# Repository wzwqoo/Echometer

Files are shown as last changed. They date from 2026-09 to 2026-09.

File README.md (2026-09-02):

# Echometer

A pocket-sized, battery-powered **ultrasonic bat detector**. It listens for
bat calls above 19 kHz, and when it hears one it records a 3.84-second
full-spectrum clip at **256 ksps** into PSRAM and serves it over its own Wi-Fi
network. Open a phone browser, download the WAV, and import it straight into
the Wildlife Acoustics **Echo Meter** app — the files carry GUANO metadata and
are accepted as Echo Meter Touch 2 Pro recordings.

No SD card, no cables, no custom phone app, no laptop in a field at midnight.

This is **v4**, the fourth board in the series. It is the first one that is
genuinely portable and the first one that doesn't clip on a close bat: the
analog front end has **six switchable gain steps from 22× to 782×**, chosen
from the web page or tracked automatically, and the whole thing runs off a
protected LiPo with charger and boost on board. See
[Design history](#design-history) for how it got here.

|  |  |
|:--:|:--:|
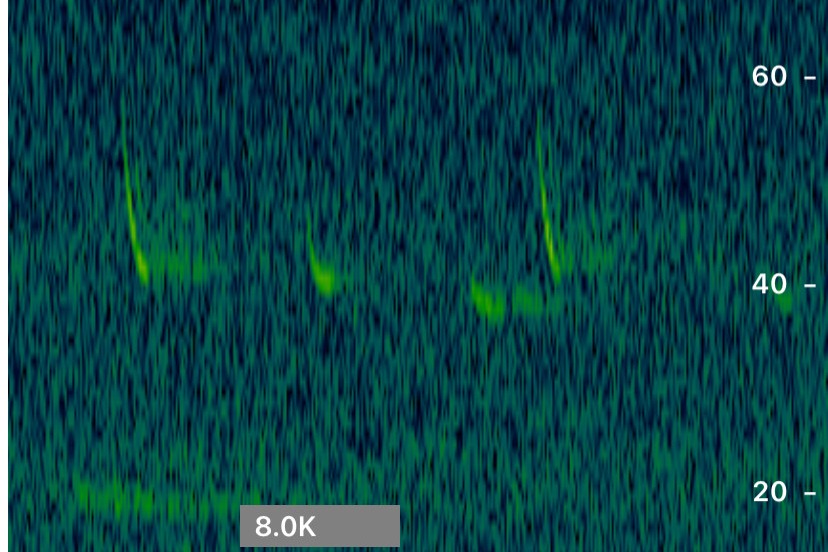
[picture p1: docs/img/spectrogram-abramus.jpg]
Echo Meter spectrogram of four downsweeping calls between roughly 40 and 55 kHz, on a 14-67 kHz axis
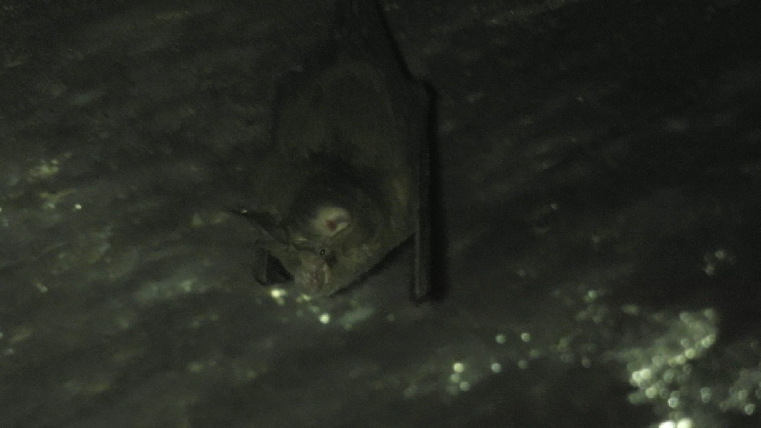
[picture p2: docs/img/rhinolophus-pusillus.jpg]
Least horseshoe bat roosting upside down on a cave ceiling
|  |  |
| **Japanese Pipistrelle**<br>*Alionoctula abramus* &mdash; recorded by this board, opened in the Echo Meter app | **Least Horseshoe Bat**<br>*Rhinolophus pusillus* &mdash; the ~108 kHz caller that set the sample rate |

---

## Contents

- [Specifications](#specifications)
- [How it works](#how-it-works)
- [Repository layout](#repository-layout)
- [Getting started](#getting-started)
- [Using it](#using-it)
- [Hardware in brief](#hardware-in-brief)
  - [Switchable gain](#switchable-gain)
  - [Power](#power)
  - [Pinout](#pinout)
- [Firmware in brief](#firmware-in-brief)
- [Errata — read before ordering the PCB](#errata--read-before-ordering-the-pcb)
- [Design history](#design-history)
- [Roadmap](#roadmap)
- [References](#references)

---

## Specifications

| | |
|---|---|
| Detection band | 19 – 128 kHz |
| Sampling | 256 ksps, 12-bit, external SAR ADC (ADCS7476) |
| Frequency resolution | 125 Hz/bin (2048-point FFT, 8 ms frames) |
| Analog gain | 6 steps, **22× – 782×** (26.9 – 57.9 dB), manual or AGC |
| Microphone | Knowles SPU0410LR5H-QB MEMS, −38 dBV/Pa, usable to ≈ 80 kHz |
| Clip length | 3.84 s (983 040 samples, 1.97 MB) |
| Clip storage | up to 8 PSRAM slots — 4 on an 8 MB module; RAM-only, lost at power-off |
| Transfer | open Wi-Fi AP `echometer` → `http://192.168.4.1` |
| File format | 16-bit mono WAV + GUANO chunk, `CHIRP_YYYYMMDD_HHMMSS.wav` |
| Compute | ESP32-S3 DevKitC-1, octal PSRAM, ESP-IDF ≥ 5.2 |
| Power | 2000 mAh LiPo, TP4056 charger @ 1 A, DW01/FS8205A protection, MT3608 boost |
| PCB | 4-layer, KiCad 10, gerbers in [`hardware/fab/`](hardware/fab/) |

## How it works

```text
                        ┌── 74HC4053 mux ──┐
                        │  (3 × GPIO)      │
                        ▼                  ▼
  ┌────────┐      ┌───────────┐      ┌──────────┐      ┌───────────┐
  │ conical│      │  OPA838   │      │  TL972   │      │ ADCS7476  │
──│  horn  │─────▶│  ×4.25/34 │─────▶│ ×5.2…23  │─────▶│ 12-bit    │
  │        │ MEMS │  stage 1  │  HP  │ stage 2  │  AA  │ 256 ksps  │
  └────────┘  mic └───────────┘      └──────────┘      └─────┬─────┘
                                                             │ I²S RX DMA
                                                             ▼
   Safari ◀── HTTP ◀── SoftAP ◀── PSRAM clip ◀── trigger ◀── 2048-pt FFT
     │                             4 × 3.84 s      >19 kHz    (esp-dsp)
     ▼                                             narrowband
  Echo Meter app                                   3 frames
```

1. Press **BOOT** to arm. The LED flashes green whenever ultrasound is present.
2. Every 2048-sample buffer is FFT'd. A detection needs a **narrowband** peak
   above 19 kHz that **persists** across 3 consecutive frames — broadband
   transients (a finger on the board, contact noise) are rejected.
3. On detection the clip streams into a PSRAM slot for 3.84 s. The LED goes
   completely silent during the write — its own drive current used to print
   evenly-spaced clicks into the spectrogram.
4. Blue flash when saved, then back to idle. Join Wi-Fi `echometer`, browse to
   `http://192.168.4.1`, download or delete clips, and set the gain.

The interesting trick is the ADC clocking. The ESP32-S3's internal ADC-DMA path
tops out near 83 ksps, nowhere near enough for a bat. So an external SAR ADC is
driven by the **I²S peripheral pretending to be an SPI master**: in 16-bit
stereo master mode the WS line toggles every 16 bit-clocks, so WS becomes the
ADC's `CS#` and BCK its `SCLK`. RX DMA captures every sample with zero
per-sample CPU, jitter-free, at an 8.192 MHz bit clock.

## Repository layout

| Path | Contents |
|---|---|
| [`hardware/`](hardware/) | KiCad 10 project — schematic, 4-layer PCB, gerbers, BOM, horn generator. See [hardware/README.md](hardware/README.md) for the analog design. |
| [`firmware/`](firmware/) | ESP-IDF application. See [firmware/README.md](firmware/README.md) for the detection logic and bring-up lessons. |
| [`firmware/main/archive/`](firmware/main/archive/) | Earlier firmware variants kept for reference — v3's original, an SD-card recorder, a board bring-up test. |
| [`docs/img/`](docs/img/) | Photographs and screenshots used in this README. |

## Getting started

**You need:** an ESP32-S3-DevKitC-1 with **octal** PSRAM, the assembled v4
board, a 2000 mAh LiPo with a JST-PH lead, and ESP-IDF ≥ 5.2.

```bash
cd firmware
. ~/software/esp-idf/export.sh              # adjust to your ESP-IDF path
idf.py build
idf.py -p /dev/ttyUSB0 flash monitor        # the COM (UART) USB-C port
```

The DevKitC-1 has two USB-C ports. **COM** (CP2102N → UART0) does flashing and
the log console and always works. If a bad flash ever bricks the app: hold
BOOT, tap RESET, release → ROM download mode, reflash over COM.

Before you build the board, read
[Errata](#errata--read-before-ordering-the-pcb) — item 1 is blocking.

## Using it

| Action | What happens |
|---|---|
| Press BOOT | Arm. LED flashes green while ultrasound is present. |
| Detection | LED silent, 3.84 s clip written to PSRAM, then blue flash. |
| Press BOOT while armed | Disarm back to idle. Presses during a write are ignored. |
| Join `echometer` (open network) | AP is up in every state. |
| `http://192.168.4.1` | Clip list, newest first: download, delete, set gain, toggle AGC. |

Clips live in RAM only — **they are lost at power-off**. Download before you
disconnect the battery.

To get a clip into the Echo Meter app on iOS: download in Safari, then
Files → share sheet → *Copy to Echo Meter*.

---

## Hardware in brief

Everything below is the summary. Full derivations — op-amp selection, mic
specs, the input common-mode budget, every filter corner, the power design,
the pinout, the acoustic horn and the bat call-level budgets — are in
[hardware/README.md](hardware/README.md).

Single channel, single 3.3 V analog rail, everything biased to mid-rail
(VREF ≈ 1.65 V). Stage 1 is a **TI OPA838** — 300 MHz GBW, decompensated,
1.8 nV/√Hz — because gain × 120 kHz has to fit inside the gain-bandwidth
product. Stage 2 is a **TI TL972**, rail-to-rail in and out, which drives the
ADC to full swing on 3.3 V. Both stages are non-inverting with a 1 kΩ leg to
VREF. The band is ≈ 19 kHz – 128 kHz: two 10 nF high-passes stacked at the
bottom, a 72 kHz RC anti-alias filter ahead of the ADC at the top.

### Switchable gain

A **74HC4053** analog mux switches extra feedback resistors **in parallel**
with a permanent one at each stage's summing node — one switch on stage 1, two
on stage 2. Parallel resistors *lower* the gain, the permanent resistors mean
the loop is never open, and the mux's Y0-when-LOW polarity means the state the
ESP32's GPIOs sit in at reset is **minimum gain, which cannot clip**.

| **Total** | dB | Clips near | Use |
|---|---|---|---|
| **22×** | 26.9 | 105 dB SPL | cave / roost, bats at arm's length |
| **51×** | 34.2 | 98 dB SPL | |
| **98×** | 39.8 | 92 dB SPL | general close work |
| **210×** | 46.4 | 86 dB SPL | default at cold boot |
| **408×** | 52.2 | 80 dB SPL | |
| **782×** | 57.9 | 74 dB SPL | distant passes, ~30 m |

Steps are 5.6–7.3 dB apart. "Clips near" is the input SPL at which the TL972
output hits its rail. The range stops at 782× because past ~800× you are
amplifying the microphone's own noise rather than signal — further reach has to
come from narrowband processing, not from the front end.

Resistor values, the switch-state table, why the three switches are split 1/2
across the stages, and why the switches sit at the summing node:
[hardware/README.md](hardware/README.md#gain--how-the-switching-works).

### Power

USB charger → cell → protection → boost to 5.31 V for the module, with the
analog rail taken off separately. The one decision worth naming here: **the
analog LDO is fed from the battery, not from the boost.** The TPS74801's
separate BIAS pin runs its control loop from +5 V so the pass FET can be driven
above VIN, which lets IN sit at the raw cell voltage. The win isn't efficiency,
it's noise — the analog rail never sees the MT3608's 1.2 MHz ripple, which no
LDO's PSRR is good at rejecting.

Two things to know before you use it:

- **Charging while running works**, but the load current means the TP4056 may
  never reach its termination threshold, so it can sit in CV at 4.2 V and the
  green LED may never come on. Don't leave it plugged in for days.
- **There is no power switch.** The board runs from the moment the cell is
  connected — unplug J6 to stop it. See errata 5 to store it charged.

Rail diagram, component values, the 5.31 V boost-margin calculation and where
to add a switch if you want one: [hardware/README.md](hardware/README.md#power).

### Pinout

ADC on GPIO 4 / 5 / 6 (I²S WS / BCK / DIN), gain select on GPIO 38 / 37 / 36
(⚠ **see errata 1**), RGB LED on 48, BOOT button on 0. Full header-pin table:
[hardware/README.md](hardware/README.md#pinout--esp32-s3-devkitc-1).

---

## Firmware in brief

ESP-IDF application, single `main.c`. Full detail — state machine, WAV/GUANO
construction, sdkconfig requirements and the bring-up lessons — is in
[firmware/README.md](firmware/README.md).

| State | Entered by | LED |
|---|---|---|
| IDLE | boot / disarm | off |
| DETECT | BOOT press | green flash while ultrasound present |
| RECORD | detection persists 3 frames | **silent** for the 3.84 s write |
| after RECORD | write finished | blue flash ~1.2 s → IDLE |

**Detection.** 2048-point real FFT per buffer via esp-dsp. Trigger requires, on
3 consecutive buffers: a bin above 19 kHz (bin ≥ 152) over
`ULTRASONIC_THRESH_COUNTS`, **and** a peak ≥ 20× the average power of the rest
of the >19 kHz band. The tonality test is what rejects broadband impulses; the
persistence test is what rejects momentary ones.

**Gain control.**

- **Web:** `http://192.168.4.1` → tap a gain. Picking one by hand turns the AGC
  off, and the choice is saved to NVS so it survives a power cycle.
- **AGC:** fast attack, slow decay. Any frame peaking above 90 % of full scale
  drops the gain one step immediately; the gain only steps back up after ~1 s
  (120 frames) below 10 %. Asymmetric on purpose — clipping happens in the
  **analog** domain before the ADC, so a clipped call is unrecoverable, while a
  symmetric AGC would pump on every gap between calls.
- **Frozen during RECORD.** A gain step mid-clip would put a discontinuity in
  the waveform and make the clip useless for absolute amplitude. The gain in
  force is latched at trigger time and written into the clip's GUANO metadata
  (`Note` plus `Echometer|Gain`), so SPL can be reconstructed offline.
- After every gain change the detector skips 2 frames while the mux's charge
  injection settles out of the summing node, so a switch is never mistaken for
  a call.

**HTTP endpoints:** `/` (clip list), `/dl`, `/del`, `/gain?i=N`, `/agc?on=0|1`.

**A note on the device identity in the metadata.** The Echo Meter app validates
the GUANO `Model` field against known Wildlife Acoustics modules and rejects
anything else, so the firmware writes `Model: Echo Meter Touch 2 Pro` — a
format this recorder genuinely matches (256 kHz, 16-bit, full-spectrum mono).
True provenance is kept in the GUANO `Note` field. Keep that in mind before
sharing files anywhere that trusts the device tag.

---

## Errata — read before ordering the PCB

Known problems with the v4 board as drawn. **Item 1 is blocking** — fix it in
the schematic before you send gerbers. The rest are things to know before you
build, not stop-ships.

**1. Two gain-select signals land on the octal-PSRAM bus.** With
`CONFIG_SPIRAM_MODE_OCT=y`, GPIO35/36/37 belong to the PSRAM controller and
cannot be used for anything else, but the PCB routes Gain S2 to J12.11
(GPIO37) and Gain S3 to J12.12 (GPIO36). The firmware already assumes the
corrected pins — `PIN_GAIN_S1/S2/S3` are GPIO 38/39/40 — so an uncorrected
board will not switch gain.
**Fix:** move S2 to J12.9 (GPIO39) and S3 to J12.8 (GPIO40). GPIO39/40 are
MTCK/MTDO, free here only because the DevKitC-1 debugs over the built-in
USB-Serial-JTAG on GPIO19/20. See
[firmware/README.md](firmware/README.md#5-gpio-choice-is-constrained-by-psram-mode).

**2. Stage 1's lowest gain step sits below the OPA838's minimum stable gain.**
The OPA838 is decompensated, with a minimum stable gain of +7; stage 1's low
setting is 4.25. The design relies on C14 (27 pF across R13) to provide the
compensation the topology needs, and 27 pF is small enough that stray
capacitance matters. If the three low gain steps ring, peak or oscillate,
this is the first place to look.

**3. The +5 V rail has ~390 mV of bias margin, and it needs verifying.** The
boost is set to 5.31 V because the TPS74801's BIAS pin must stay at least
1.62 V above the 3.3 V output, i.e. ≥ 4.92 V. Measure the sag on a real board:
if +5 V dips below 4.92 V during a Wi-Fi TX burst, the LDO loses bias headroom
and the analog rail glitches during exactly the moments you transmit.

**4. The SD footprint (J5) is +5 V and unbuffered.** Pin 5 is fed +5 V and the
SPI lines are not level-shifted, so J5 accepts an SD **module** with its own
regulator and level shifters — never a bare card socket. The current firmware
does not use it; leave it unpopulated unless you are building the archived
recorder.

**5. There is no power switch, and the cell will over-discharge in storage.**
The boost's EN is tied to its own input, so the board runs from the moment the
cell is connected. Standby drain as built is 50–120 mA, which flattens
2000 mAh in 17–40 hours and then parks the cell at the DW01's 2.4 V cutoff —
bad for lithium.
**Fix:** unplug J6 for storage and store the cell charged. If you add a switch,
put it in the `Lipo+ → L1 / U8.5` branch, **not** on the boost's EN pin — the
MT3608 is asynchronous, so `Lipo+ → L1 → D3 → +5V` is a permanent DC path that
survives disabling the boost. See
[hardware/README.md](hardware/README.md#charging-and-switching-both-with-caveats).

**6. Several schematic symbols carry stale part numbers.** R13, R23/R25, R24
and R26 inherit a 24 kΩ `Part#` / `LCSC Part #` from their previous value, and
C16 inherits a 10 nF one. Those fields are cleared in the checked-in
[`hardware/v4.csv`](hardware/v4.csv), so **ordering from the CSV is safe** —
but fix the symbol properties before the next `kicad-cli sch export bom`.

---

## Design history

Four boards, each one built to answer the question the previous one raised.

| | v1 | v2 | v3 | v4 |
|---|---|---|---|---|
| **Compute** | STM32F401CBU6 | STM32F446RET6 (Nucleo) | ESP32-S3 | ESP32-S3 |
| **Sampling** | internal ADC, free-running DMA | internal ADC, TIM2-gated **240 ksps** | external ADCS7476 via I²S, **256 ksps** | same |
| **Detection** | none — raw recorder | CMSIS-DSP FFT, >19 kHz threshold | + tonality + persistence | same |
| **Storage** | micro-SD (SPI1, FatFS) | micro-SD (SPI3, FatFS) | 4 × PSRAM slots | up to 8 slots |
| **Retrieval** | pull the card / USB CDC | pull the card / UART + Python | **Wi-Fi + Safari + GUANO WAV** | same |
| **Gain** | analog board, fixed | fixed 121× | fixed 625× | **6 steps, 22×–782× + AGC** |
| **Listening** | heterodyne + FD to a speaker | — | — | — |
| **Power** | 9 V in, LM2574 + LDOs | dev-board USB | USB (browned out) | **LiPo + charger + protection + boost** |

### v1 — does the analog even work?

A custom STM32F401CBU6 mainboard plus a separate analog board carrying the
classic hobbyist bat-detector chain: SPU0410 MEMS mic → LM358 preamp → CD4066
mixer switched by a TLC555 → LM386 → speaker, i.e. **heterodyne and frequency
division straight to your ears**. Two small preamp boards (one OPA838, one
TL972) were spun alongside it to compare op-amps on real signals.

The MCU side ran FreeRTOS with three tasks: ADC1 in continuous DMA into a
double buffer, a ring buffer feeding FatFS on a micro-SD over SPI1, and a
debounced button. Power was 9 V in through an LM2574 buck and NCP718/NCP163
LDOs.

**What it proved:** the microphone, the horn and the amplifier chain all work,
and you can hear bats. **What it cost:** hearing a bat isn't recording one —
the heterodyne path destroys the signal it demodulates. There was no detection
logic at all, so recording was start/stop by hand. The ADC free-ran on a
software start with no timer trigger, so the sample clock had jitter. And
splitting analog and digital across two boards joined by 4-pin headers was an
invitation to pickup.

**→ v2:** drop the speaker path entirely, go full-spectrum digital, put the ADC
on a hardware time base, and add a real FFT detector.

### v2 — detect it, don't just hear it

A Nucleo-F446RE with a custom analog + SD daughterboard: SPU0410 →
**OPA838 → TL972**, single 3.3 V rail, mid-rail bias — the two-stage topology
that survives into v4. TIM2 TRGO gates ADC1 at exactly **240 ksps** into a
2 × 2048 DMA double buffer, and each half-buffer goes through
`arm_rfft_fast_f32` from CMSIS-DSP: 117 Hz/bin, trigger on any bin ≥ 163
(>19 kHz) above 50 counts. Detect and record are two states with different LED
blink rates; recording writes raw `uint16` samples to FatFS over SPI3 with an
`f_sync` every 100 writes. Python tools (`bat_record.py`, `bat_viewer.py`,
`bat_waveform.py`) pull captures over the serial port and plot them.

Gain went from 11× per stage (**121×** total) to 25× per stage (**625×**)
during bring-up. At 121× real calls sat barely above the noise floor; the 5×
jump is what moved detection from marginal to reliable.

**What it cost:** 240 ksps means a 120 kHz Nyquist, and that was the internal
ADC's practical ceiling — the target species here, *Rhinolophus pusillus*, calls
at ~108 kHz, right at the edge. Getting files off meant pulling the card or
dumping over serial. And the gain was still a soldered constant.

**→ v3:** an external ADC fast enough to have real margin above 108 kHz, and a
way to get files onto a phone in the field.

### v3 — fast enough, and wireless

ESP32-S3 with an external **ADCS7476** 12-bit SAR clocked by the I²S
"WS-as-CS" trick at **256 ksps** — zero per-sample CPU, 128 kHz Nyquist.
Detection moved to esp-dsp and gained the two tests that make it usable
outdoors: **tonality** (peak bin ≥ 20× the mean power of the rest of the band)
and **persistence** (3 consecutive frames). Clips go to PSRAM — four 3.84 s
slots in 8 MB — and are served over a SoftAP as WAVs with a **GUANO** metadata
chunk that the Echo Meter iPhone app accepts. Two mics and two full channels,
fixed 625×.

That combination is what made it a real detector: no card, no cable, and a
phone app that already knows how to draw a spectrogram.

**What it cost, and this is the whole reason v4 exists:**

- **625× clipped constantly.** Roughly 9 out of 10 close calls railed the
  second stage, smearing the spectrogram into broadband bars and false
  harmonics. Clipping happens in the analog domain, so no amount of digital
  processing recovers it — and there was no way to turn the gain down.
- **It browned out.** Wi-Fi RF calibration and TX bursts (300–400 mA on top of
  octal PSRAM) tripped the brownout detector on marginal USB supplies. Inline
  USB "noise filter" dongles made it *worse* — series resistance is exactly the
  problem. Downloads, being the heaviest sustained RF load, failed first.
- **A floating ADC input false-triggered on touch.** Fixed in firmware by the
  tonality and persistence tests; the hardware fix was left for the next spin.
- **The LED printed clicks into the spectrogram.** The WS2812's RMT refresh
  coupled into the front end, so the firmware learned to keep it silent for the
  whole capture window.
- **The mic-supply filter did nothing.** 10 Ω + 110 nF corners at 159 kHz —
  above the band it was supposed to clean.

**→ v4:** make the gain adjustable, and stop feeding a 400 mA radio through a
thin cable.

### v4 — portable, and it doesn't clip

| Area | v3 | v4 |
|---|---|---|
| Gain | fixed 625× | **6 steps, 22×–782×**, web-selectable + AGC |
| Gain control | — | 74HC4053 mux at both summing nodes, 3 GPIOs |
| Channels | 2 mics, 2× OPA838 + 2× TL972 | 1 mic, 1× OPA838 + 1× TL972 — gain replaces the second channel |
| Power source | USB only | LiPo 2000 mAh + charger + protection + boost |
| Charging | — | TP4056 @ 1 A, red/green status LEDs |
| Cell protection | — | DW01 + FS8205A, low-side |
| 3V3 analog rail | LDO from 5 V (boost output) | LDO **from the battery**, bias from 5 V |
| Mic supply filter | 10 Ω + 110 nF (159 kHz — did nothing) | **100 Ω + 10 µF (159 Hz)** |
| Anti-alias | 100 Ω + 10 nF (159 kHz, above Nyquist) | **100 Ω + 22 nF (72 kHz)** |
| Wi-Fi burst reservoir | external | **470 µF on board** at the module header |
| Floating ADC input | v3 erratum — false triggers | driven from the op amp through 100 Ω; can't float |
| Clip metadata | timestamp only | **gain recorded in GUANO** |

The trade worth naming: v4 gives up v3's second channel. Two mics at two fixed
gains is the other classic way to get wide dynamic range — digitise both, keep
whichever didn't clip, zero AGC artifacts. One switched channel costs a mux and
some AGC logic but buys 31 dB of range instead of one fixed step, and it frees
the board area that paid for the battery.

## Roadmap

Carried forward, in rough order of value:

- **Ring buffer for pre-trigger audio.** The clip currently starts at the
  triggering buffer, so the calls *before* detection fired are lost. This is
  the single biggest capture upgrade left — every serious passive recorder
  keeps a few seconds of pre-roll.
- **Adaptive trigger.** A running noise-floor estimate (exponential moving
  average of ultrasonic-band energy) rather than the fixed
  `ULTRASONIC_THRESH_COUNTS`. Note that with variable gain a fixed threshold
  now means a *different* absolute sensitivity at each step, which makes this
  more pressing than it was in v3.
- **Call-shape gating.** Require a swept FM component, plausible duration
  (~2–20 ms) and inter-pulse interval, to reject bush-crickets and machinery.
  The tonality + persistence test is a first cut at this.
- **Duty cycling** for unattended overnight runs — light sleep between checks,
  or a low-power always-on trigger path that wakes full recording on a hit.
- **Pause the AP during capture**, so no TX spike or RF pickup can coincide
  with the 3.84 s sampling window.

For reference, AudioMoth uses a plain amplitude threshold; Song Meter /
Kaleidoscope use band-limited energy triggers; Anabat uses zero-crossing
frequency division; and the most advanced run an on-device CNN
(e.g. BatDetect2) to detect and classify in real time.

## References

- [GUANO metadata specification](https://guano-md.org)
- TI [OPA838](https://www.ti.com/lit/gpn/opa838), TL972, ADCS7476, TPS74801 datasheets
- Knowles SPU0410LR5H-QB datasheet and Ultrasonic Application Note AN17
- [AudioMoth](https://www.openacousticdevices.info/) — reference low-power design
- [BatDetect2](https://github.com/macaodha/batdetect2) — CNN call detection and classification

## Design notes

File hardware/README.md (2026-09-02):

# Hardware — analog front end, power, PCB and acoustics

KiCad 10 project (`v4.kicad_pro`, schematic + 4-layer PCB), fabrication outputs
in [`fab/`](fab/), BOM in [`v4.csv`](v4.csv), and the parametric acoustic-horn
generator [`ultrasonic_horn_freecad.py`](ultrasonic_horn_freecad.py).

The schematic is split over two sheets: `v4.kicad_sch` (root) and
`MCU.kicad_sch` (everything — front end, ADC, power, module headers).

> Read the errata in the [top-level README](../README.md#errata--read-before-ordering-the-pcb)
> before ordering. Item 1 is blocking: two of the three gain-select signals land
> on the octal-PSRAM bus and must be moved.

---

## Analog front end

### Transducer

**Knowles SPU0410LR5H-QB**, one fitted. An analog MEMS mic with usable response
through the target bat band; its raw output is small — tens of millivolts for a
loud, close call — so it must be amplified and biased into the ADC's input
range before sampling.

| Parameter | Value |
|---|---|
| Type | analog MEMS (SiSonic), bottom-port, omnidirectional |
| Sensitivity | −38 dBV/Pa (±3 dB) ≈ 12.6 mV/Pa @ 94 dB SPL, 1 kHz |
| SNR | 63 dB(A) → self-noise ≈ 31 dB(A) SPL |
| Frequency response | ~100 Hz → usable to ≈ 80 kHz (rising resonance ~20–25 kHz) |
| Max acoustic input | ≈ 120 dB SPL |
| Supply / current | 1.5–3.6 V / ~123 µA |
| Output impedance | ~200 Ω |
| Package | 3.76 × 2.95 × 1.10 mm, 0.25 mm port |

The 0.25 mm acoustic port sits at the throat of the conical horn.

### Op-amp choice

The amplifier must pass the full ultrasonic band **and** apply large gain
without rolling off, which sets a hard requirement on gain–bandwidth product:
`GBW ≥ gain × 120 kHz`. Two devices:

| Stage | Part | Why |
|---|---|---|
| 1st gain | **TI OPA838** (OPA838IDBVR) | 300 MHz GBW, decompensated (min stable gain +7), 1.8 nV/√Hz, ~1 mA |
| 2nd gain / ADC driver | **TI TL972** (TL972IDR) | dual rail-to-rail I/O, 12 MHz GBW — drives the ADC to full swing on 3.3 V |

Both run single-supply and bias the signal to **mid-rail (VREF ≈ 1.65 V)** so
the AC waveform swings symmetrically inside the ADC's 0–3.3 V window. A **TI
TPS74801** low-noise LDO supplies the analog rail and VREF, so digital
switching noise doesn't couple into the µV-level mic signal.

Note the OPA838's decompensation: its minimum stable gain is +7, which is a
real constraint on the gain-step table below — stage 1's low setting of 4.25
would be unstable on its own, and is only usable because C14 (27 pF across
R13) provides the compensation the topology needs.

### Gain — how the switching works

Both stages are non-inverting with a 1 kΩ leg to VREF. Each has a
**permanent** feedback resistor, and a **74HC4053** analog mux switches further
resistors in **parallel** with it, which *lowers* the gain.

| Stage | Amp | Rg | Permanent Rf | Switched in parallel | Gains |
|---|---|---|---|---|---|
| 1 | OPA838 (U3) | R6 = 1 k | R13 = 33 k | R26 = 3k6 via switch 1 | 34 / 4.25 |
| 2 | TL972B (U2) | R12 = 1 k | R25 = 22 k | R23 = 22 k (sw 2), R24 = 6k8 (sw 3) | 23 / 12 / 6.2 / 5.2 |

Three design decisions are load-bearing here:

**The permanent resistors are never switched out.** The loop is closed in every
mux state, including the ~300 ms before firmware runs and the instant the mux
transitions. Nothing can rail.

**The polarity is chosen so reset means quiet.** The 4053 selects Y0 — resistor
connected, parallel combination, *lower* gain — when its select pin is **LOW**.
GPIOs sit low at reset, so the board wakes at minimum gain, which cannot clip.

**The switches sit at the summing node**, mux common to the op-amp inverting
input and the resistors to Y0. Both sides of a closed switch are therefore at
virtual ground, so the mux's on-resistance sees an almost constant voltage.
That is what keeps the 4053's on-resistance nonlinearity out of the signal —
put the switch anywhere the voltage swings and it becomes a distortion source.

**Why the switches are split 1 / 2 across the stages.** Switching resistors in
parallel adds conductances, so the achievable ratio within one stage is bounded
— a single stage can only span about 18 dB however you pick the values. Two
stages multiply, giving the full 31 dB.

### The six steps

| S1 | S2 | S3 | Stage 1 | Stage 2 | **Total** | dB | Clips near |
|---|---|---|---|---|---|---|---|
| 0 | 0 | 0 | 4.25 | 5.2 | **22×** | 26.9 | 105 dB SPL |
| 0 | 0 | 1 | 4.25 | 12 | **51×** | 34.2 | 98 dB SPL |
| 0 | 1 | 1 | 4.25 | 23 | **98×** | 39.8 | 92 dB SPL |
| 1 | 1 | 0 | 34 | 6.2 | **210×** | 46.4 | 86 dB SPL |
| 1 | 0 | 1 | 34 | 12 | **408×** | 52.2 | 80 dB SPL |
| 1 | 1 | 1 | 34 | 23 | **782×** | 57.9 | 74 dB SPL |

Steps are 5.6–7.3 dB apart. "Clips near" is the input SPL at which the TL972
output hits its rail, for the SPU0410 at −38 dBV/Pa with ~1.45 V of peak swing.

Three switches give 8 states, not 6. The two omitted (177× and 26×) sit within
1.5 dB of a neighbour, and that bunching is unavoidable: the four states of two
parallel switches always satisfy `G(both) = G(a) + G(b) − G(neither)`, so they
cannot be spaced evenly.

### Input common-mode headroom — checked, and why VREF must stay mid-rail

Neither amp has a rail-to-rail *input* stage, and both stages are
non-inverting, so the + input carries signal rather than sitting still. On a
3.3 V rail:

| | Spec | Window on 3.3 V | Worst-case swing here | Margin |
|---|---|---|---|---|
| TL972 (U2) | V<sub>ICM</sub> = VCC− + 1.15 … VCC+ − 1.15 | **1.15 – 2.15 V** | 1.371 – 1.929 V (at A2 = 5.2) | 221 mV |
| OPA838 (U3) | VS− − 0 … VS+ − 1.3 (over temp) | **0 – 2.00 V** | 1.584 – 1.716 V | 284 mV |

Both pass. The TL972's is the tighter one and it appears at the *lowest* gain
step, where the output is clipping at ±1.45 V and its + input therefore has to
swing ±279 mV. The OPA838 is never stressed because its + input only ever
carries the mic-level signal, at most ±66 mV — the mic itself runs out
(AOP ≈ 120 dB SPL) at about the same point its 2.0 V ceiling would be reached.

The useful consequence: the safe window is the **intersection**, 1.15 – 2.00 V,
and VREF at 1.65 V sits near its centre. Do not "improve" headroom by moving
VREF down — 1.15 V is a hard floor for the TL972, and anything below ~1.4 V
starts eating the margin you gained at the top.

### Why the gain stops at 782×

The SPU0410's own noise integrated over 20–120 kHz is around **38 dB SPL**, and
a bat at 30 m arrives at roughly 30 dB SPL. Past ~800× you are amplifying mic
noise, not signal.

v3's jump from 121× to 625× helped because at 121× the ADC's LSB was still
competing with the mic noise; at 782× the mic dominates and more gain buys
nothing. Further range has to come from narrowband processing — FFT bin energy,
matched filter — not from the front end.

### Filtering — ultrasonic only

| Element | Value | Corner | Purpose |
|---|---|---|---|
| C12 + (R3 + mic Zout ≈ 1.3 k) | 10 nF | 12.2 kHz | HP, mic → stage 1 |
| C13 + (R15 + R10 ≈ 1.1 k) | 10 nF | 14.5 kHz | HP, stage 1 → stage 2 |
| *both together* | | **≈ 19 kHz −3 dB** | −33 dB at 2 kHz |
| C14 across R13 | 27 pF | 179 kHz | stage-1 LP / compensation |
| C15 across R25 | 27 pF | 268 kHz | stage-2 LP / compensation |
| R17 + C16 | 100 Ω + 22 nF | 72 kHz | anti-alias ahead of the ADC |
| R18 + C19 | 100 Ω + 10 µF | 159 Hz | mic **supply** filter (not signal) |

Two of these look similar and do opposite jobs, and v3 got one of them wrong.
R18/C19 is a **power-supply** filter on the mic's VDD pin — it wants its corner
far *below* the band, and 159 Hz gives about 48 dB of rejection at 40 kHz.
v3 used 10 Ω + 110 nF, which corners at 159 kHz and therefore did essentially
nothing. C12/C13 are the **signal** high-pass and want their corners *at* the
band edge.

The anti-alias filter had the same class of bug in v3: 100 Ω + 10 nF corners at
159 kHz, above the 128 kHz Nyquist, so it wasn't anti-aliasing anything. 22 nF
brings it to 72 kHz.

Keeping R6/R12 at 1 kΩ is what let both 27 pF compensation caps stay. Scaling
the network up 10× for resistor accuracy would have demanded ~2 pF caps, which
are not buildable against stray capacitance. Mux on-resistance instead adds
1.5 % error at the 33 k tap and 4 % at the 6k8 tap — irrelevant for a detector.

---

## Digital acquisition

Sampling is done by an **external 12-bit SAR ADC (ADCS7476, rated 1 MSPS)** run
at **256 ksps → 128 kHz Nyquist**, covering the full bat band. The ESP32-S3's
built-in ADC-DMA path tops out near 83 ksps — far too slow — so the external
ADC is clocked with a hardware trick:

- The **I²S peripheral** runs as master, 16-bit **stereo**, so its **WS line
  toggles every 16 bit-clocks**.
- **WS → ADC CS**, **BCK → SCLK**, **SDATA → I²S DIN**. WS-low frames each
  conversion (16 clocks readout); WS-high is the re-track gap.
- I²S RX DMA captures every sample jitter-free with **zero per-sample CPU**.
  At 256 ksps the bit clock is `256000 × 2 × 16 = 8.192 MHz`.

Buffers of **2048 samples** (one FFT frame, 8 ms) feed the detector —
125 Hz/bin resolution; the detection band starts at bin 152 (19 kHz). See
[../firmware/README.md](../firmware/README.md) for the detection logic and the
bit-alignment quirk in the returned word.

The ADC input is driven from the TL972 output through R17 (100 Ω), so unlike
v3 it can never float. A floating ADC input is an antenna, and touching it
false-triggered v3's detector every time.

### Signal levels & detection budget

| Quantity | Value |
|---|---|
| ADC | 12-bit, full scale 4095 counts over 3.3 V |
| Bias point | VREF ≈ 1.65 V |
| Raw transducer signal (close call) | ~33–50 mV |
| Gain range | 22× – 782×, six steps |
| Detection band | > 19 kHz |
| Known interferer | ~50 kHz USB switching noise falls **inside** the band |

The FFT detection threshold (`ULTRASONIC_THRESH_COUNTS`) sits a few dB above
the *amplified* noise floor. Because the gain is now variable, that fixed
count threshold represents a different absolute sensitivity at each step — see
the roadmap note about an adaptive trigger.

---

## Power

```text
USB ──▶ TP4056 ──▶ [cell] ──▶ DW01/FS8205 ──▶ Lipo+ ─┬─▶ MT3608 ──▶ +5V ──▶ ESP32 module
                                                     │              └──▶ TPS74801 BIAS
                                                     └──────────────────▶ TPS74801 IN ──▶ +3V3 analog
```

| Block | Part | Setting |
|---|---|---|
| Charger | TP4056 (U5) | R7 = 1.2 k → **1 A** (0.5 C into 2000 mAh); thermal pad on GND |
| Protection | DW01 (U6) + FS8205A (U7) | low-side, R20 100 Ω + C25 100 nF, R8 1 k on CS |
| Boost | MT3608 (U8) | L1 4.7 µH, D3 SS34, R21 150 k / R22 19.1 k → **5.31 V** |
| Analog LDO | TPS74801 (U10) | IN from Lipo+, BIAS + EN from +5 V, R11 31.2 k / R9 10 k → **3.30 V** |
| Wi-Fi reservoir | C28 470 µF | at the module header |
| Status | D1 red / D2 green | TP4056 CHRG / STDBY |

### The LDO is fed from the battery, not from the boost

That is the whole point of the TPS74801's separate BIAS pin. BIAS runs the
control loop and the gate driver, so the pass FET can be driven *above* VIN.
That lets IN sit at the raw cell voltage (3.0–4.2 V) and drop only ~50 mV at
the ~25 mA the analog side draws.

The win isn't efficiency — it's noise. Routed the obvious way (LDO fed from the
boost output), the analog rail inherits the MT3608's 1.2 MHz switching ripple,
and no LDO's PSRR is good at 1.2 MHz. Feeding it from the cell means the analog
rail never sees the switcher at all.

**Boost output is 5.31 V, not 5.0 V, and that is deliberate.** BIAS must stay
at least 1.62 V above the 3.3 V output, i.e. ≥ 4.92 V. At 5.1 V there was only
180 mV of margin — about what a Wi-Fi TX burst eats. Measure the sag on a real
board; if +5 V dips below 4.92 V during TX, the LDO loses bias headroom and the
analog rail glitches during exactly the moments you transmit.

### Charging and switching, both with caveats

**Charging while running works** — the cell buffers everything — but the load
current means the TP4056 may never see its termination threshold. It can sit in
CV at 4.2 V indefinitely and the green LED may never come on. Don't leave it
plugged in for days.

**There is no power switch.** The boost's EN is tied to its own input, so the
board runs from the moment the cell is connected; unplug J6 to stop it. Standby
drain as built is 50–120 mA, which flattens 2000 mAh in 17–40 hours and then
parks the cell at the DW01's 2.4 V cutoff — bad for storage.

If you add a switch, put it in the **`Lipo+ → L1 / U8.5` branch**, not on the
boost's EN pin. The MT3608 is asynchronous, so `Lipo+ → L1 → D3 → +5V` is a
permanent DC path: disabling the boost leaves the module's regulator powered
anyway. Breaking the boost input kills that path and still leaves the charger
connected.

---

## Pinout — ESP32-S3 DevKitC-1

| Function | Header pin | GPIO |
|---|---|---|
| ADC CS (I²S WS) | J11.4 | 4 |
| ADC SCLK (I²S BCK) | J11.5 | 5 |
| ADC SDATA (I²S DIN) | J11.6 | 6 |
| SD nCS / MOSI / SCK / MISO | J11.16–19 | 10 / 11 / 12 / 13 |
| +5 V / GND | J11.21 / J11.22 | — |
| Gain S1 | J12.10 | 38 |
| Gain S2 | J12.11 | 37 ⚠ move to J12.9 (GPIO39) |
| Gain S3 | J12.12 | 36 ⚠ move to J12.8 (GPIO40) |
| RGB LED | on module | 48 |
| Button | on module | 0 (BOOT) |

The SD lines are wired but unused by the current firmware; J5 must be an SD
**module** with its own regulator and level shifters, since it is fed +5 V on
pin 5 and the SPI lines are unbuffered.

---

## Acoustics — the conical horn

[`ultrasonic_horn_freecad.py`](ultrasonic_horn_freecad.py) is a parametric
generator for a conical horn that concentrates incoming ultrasound onto the mic
port. It is free SNR, ahead of the electronics.

| Parameter | Value |
|---|---|
| Profile | conical |
| Throat Ø (mic end) | 0.30 mm (just over the 0.25 mm mic port) |
| Mouth Ø (open end) | 28 mm (≈ 3.5 × wavelength at 45 kHz) |
| Length | 50 mm |
| Flare half-angle | ≈ 15.9° |
| Wall thickness | 0.5 mm |
| Optimised band | 40–50 kHz |
| Print | resin 25 µm (vertical), or FDM 0.12 mm / 100 % infill |

At 108 kHz the 28 mm mouth is ~8.8 wavelengths across — well above cutoff, so
the horn still delivers strong on-axis gain, just with a narrower beam that
must be aimed more precisely.

---

## Bat call levels, directivity and detection range

> Engineering **estimates** for sizing the front end — not species-accurate
> field data.

### Source levels

| Call type / example | Peak freq | SL @ 10 cm | ≈ @ 1 m | Notes |
|---|---|---|---|---|
| Loud open-air hawkers (*Nyctalus*, *Eptesicus*, *Pipistrellus*) | 25–50 kHz | 120–130 dB SPL | 100–110 dB SPL | loudest; FM/QCF sweeps |
| Horseshoe bats (*Rhinolophus*, CF) | 80–110 kHz | 105–120 dB SPL | 85–100 dB SPL | constant-frequency |
| "Whispering" gleaners (*Myotis*, *Plecotus*) | 40–90 kHz | 85–100 dB SPL | 65–80 dB SPL | very quiet, short range |

Cross-reference this against the "clips near" column in the gain table: a loud
hawker at a few metres wants the 22× or 51× step, while a distant pass wants
782×. That 31 dB spread is exactly the range v3's single fixed 625× could not
cover.

### Target species — least horseshoe bat (*Rhinolophus pusillus*)

| Parameter | Value |
|---|---|
| Call type | CF–FM (long constant-frequency tone + short FM tails) |
| Dominant CF | ≈ 106–112 kHz (~108 kHz typical) |
| Source level | moderate, ~80–90 dB SPL @ 1 m |
| FFT bin at 108 kHz | ≈ 864 (of 1024) — comfortably under the 128 kHz Nyquist |
| Est. on-axis range | **~7–9 m** (air absorption ~3.9 dB/m at this frequency) |

Consequences for the design:

- **A fast external ADC is mandatory.** At 108 kHz the call needs > 216 ksps;
  an MCU's internal ADC at 83 ksps could not see this species at all, and even
  v2's 240 ksps left it at the very edge of the band. Hence the ADCS7476 at
  256 ksps.
- **The narrowband CF tone is the easy case for the FFT detector** — its energy
  piles into one bin. Narrowing the detection window to ~100–115 kHz (bins
  ~800–920) would target this species specifically and reject the ~50 kHz USB
  noise interferer entirely.

### Directivity

| Source of directivity | Typical | Effect |
|---|---|---|
| Bat call emission | forward lobe, −3 dB half-angle ~30–40° | a bat not facing you arrives 10–20 dB weaker |
| Bare SPU0410 mic | omnidirectional | no aiming, no acoustic gain |
| With conical horn | directional lobe | +on-axis SNR/range, must be pointed |

### Estimated detection range

Loud bat, SL = 110 dB SPL @ 1 m on-axis; minimum detectable ≈ 40 dB SPL:

| Frequency | Air absorption α | Est. max range |
|---|---|---|
| 20 kHz | ~0.6 dB/m | ~60 m |
| 40 kHz | ~1.3 dB/m | ~30 m |
| 80 kHz | ~2.9 dB/m | ~16 m |
| 120 kHz | ~4.2 dB/m | ~12 m |

Optimistic ceilings — quiet bats, off-axis calls, and weather cut these
substantially.

---

## Bill of materials

Full BOM in [`v4.csv`](v4.csv), regenerated from the schematic with
`kicad-cli sch export bom`. The parts that define the design:

| Part | Qty | Role |
|---|---|---|
| SPU0410LR5H-QB | 1 | MEMS ultrasonic microphone |
| OPA838IDBVR | 1 | 1st gain stage (300 MHz GBW) |
| TL972IDR | 1 | 2nd gain / ADC driver (RRIO) |
| 74HC4053D | 1 | 3× SPDT analog mux — the gain switch |
| ADCS7476AIMFX/NOPB | 1 | 12-bit 1 MSPS SAR ADC |
| TPS74801DRCR | 1 | low-noise LDO (analog rail / VREF) |
| TP4056 | 1 | LiPo charger, 1 A |
| DW01 + FS8205A | 1 + 1 | cell protection |
| MT3608 | 1 | boost to 5.31 V |
| conical horn (`ultrasonic_horn_freecad.py`) | 1 | acoustic gain / directivity |

**Known BOM issue:** several passive symbols still carry the `Part#` and
`LCSC Part #` of their *previous* value — R13, R23/R25, R24 and R26 inherit a
24 kΩ part number, and C16 inherits a 10 nF one. Those fields are cleared in
the checked-in `v4.csv`, so ordering from it is safe, but fix the symbol
properties before the next export.

`altium_ascii_to_kicad.py` is a helper for importing Altium ASCII footprints
into the KiCad library; it is not part of the build.

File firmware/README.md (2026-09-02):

# Firmware — ESP32-S3 chirp catcher

ESP-IDF (≥ 5.2) application. On a button press it arms an FFT-based ultrasonic
detector; on detection it records a 3.84 s clip at 256 ksps into PSRAM and
serves it as an Echo-Meter-compatible WAV over a Wi-Fi SoftAP. The analog gain
is switched from the same web page, or tracked automatically.

Everything lives in [`main/main.c`](main/main.c).

## Build & flash

```bash
. ~/software/esp-idf/export.sh   # ESP-IDF >= 5.2
idf.py build
idf.py -p /dev/ttyUSB0 flash monitor
```

The DevKitC-1 has two USB-C ports: **COM** (CP2102N → UART0) is used for
flashing *and* the log console and always works; **USB** (native OTG,
GPIO19/20) is unused by the current firmware. If a bad flash ever bricks the
app: hold BOOT, tap RESET, release — ROM download mode, reflash over COM.

Key sdkconfig settings (already in the checked-in `sdkconfig`):

| Setting | Value | Why |
|---|---|---|
| `CONFIG_SPIRAM` + `_MODE_OCT` + `_SPEED_80M` | y | octal PSRAM for clip slots (quad modules: use `_MODE_QUAD`, 2 MB → 1 slot) |
| `CONFIG_ESP_CONSOLE_UART_DEFAULT` (UART0) | y | console on the COM port |
| `CONFIG_PARTITION_TABLE_CUSTOM` | `partitions.csv` | 4 MB factory app |

Wi-Fi TX power is left at the default max — see lesson 2 for why the earlier
cap was removed.

## State machine & LED

| State | Entered by | LED |
|---|---|---|
| IDLE | boot / disarm | off |
| DETECT (armed) | BOOT button press | off while quiet, **green flash** while ultrasonic is being detected |
| RECORD | detection persists 3 FFT frames | **off/silent** for the 3.84 s write (see below) |
| after RECORD | write finished | **blue flash** ~1.2 s, then off → IDLE |
| error (no PSRAM slot, …) | — | red blink |

**Why the LED is off during RECORD:** the WS2812 is driven over RMT on GPIO48,
and every refresh is a pulse burst that couples into the high-gain analog front
end — a periodic LED refresh during capture printed evenly-spaced broadband
clicks into the spectrogram. So the LED only ever refreshes *outside* the
sampling window: green while detecting (before the clip), silent during the
write, blue flash after. `LED_OFF` touches the strip once on entry then stays
completely idle.

Pressing the button in DETECT disarms back to IDLE; presses during RECORD are
ignored. Wi-Fi (`echometer`, open, `http://192.168.4.1`) is up in every state.

## Signal path

- **ADC via I²S "WS-as-CS".** The S3's internal ADC tops out around 83 ksps,
  far too slow. An external ADCS7476 (12-bit SAR) is clocked by the I²S
  peripheral in 16-bit stereo master mode — WS toggles every 16 bit-clocks and
  drives the ADC's CS, BCK drives SCLK, and RX DMA captures SDATA with zero
  per-sample CPU. At 256 ksps the bit clock is 8.192 MHz; usable Nyquist is
  128 kHz. One 16-bit sample per WS period, so the "left" slot is the data and
  the right is discarded.
- **Bit alignment.** The ADC emits 4 leading zeros then D11..D0, and standard
  I²S delays MSB by one BCK, so the word arrives shifted. Mask and shift in
  firmware rather than fighting the peripheral.
- **Detection.** 2048-point real FFT (esp-dsp) per buffer — 125 Hz/bin, 8 ms
  per frame. Trigger requires, on `DETECT_CONSEC` = 3 consecutive buffers: a
  bin above 19 kHz (bin ≥ 152) over `ULTRASONIC_THRESH_COUNTS`, **and** a peak
  ≥ `CHIRP_TONALITY_MIN` = 20× the average power of the rest of the >19 kHz
  band. See lesson 3 for why both tests exist.
- **Clips.** `CLIP_BUFS` = 480 buffers = 983 040 samples = 3.84 s = 1.97 MB.
  Slots are allocated from PSRAM at boot — up to `MAX_CLIP_SLOTS` = 8, stopping
  when free PSRAM would drop below `SPIRAM_RESERVE` = 512 kB, so an 8 MB module
  yields four. Oldest is overwritten. **Clips are RAM-only and lost at
  power-off.**
- **WAV serving.** 44-byte PCM header + samples + a trailing **GUANO** metadata
  chunk; filenames `CHIRP_YYYYMMDD_HHMMSS.wav`. There is no RTC on board — the
  clock is seeded from the firmware build time at boot.

## Gain control

New in v4. Three GPIOs drive a 74HC4053 that switches feedback resistors in
parallel at both amplifier stages; see
[../hardware/README.md](../hardware/README.md) for the analog side.

| | |
|---|---|
| `PIN_GAIN_S1/S2/S3` | GPIO **38 / 39 / 40** (note: the PCB routes S2/S3 to 37/36 — see errata 1 in the top-level README) |
| `GAIN_STEPS[]` | the six-step table, each with its 4053 levels, total gain and approximate clipping SPL |
| `GAIN_DEFAULT` | index 3 = 210× — a sane cold start |
| `gain_apply()` / `gain_init()` | drives the three GPIOs; restores the saved step from NVS |
| `agc_update()` | fast-attack / slow-decay tracker, returns true when it moved |
| `/gain?i=N` | set a step, and turn the AGC off |
| `/agc?on=0\|1` | toggle the AGC |
| `clip_slot_t.gain` | latched at trigger, shown in the clip list, written to GUANO |

**The AGC is asymmetric on purpose.** Any frame peaking above
`AGC_ATTACK_LEVEL` (90 % of full scale) drops the gain one step *immediately*;
the gain only steps back up after `AGC_DECAY_FRAMES` = 120 frames (~1 s) below
`AGC_DECAY_LEVEL` (10 %). Clipping happens in the analog domain, before the
ADC, so a clipped call is unrecoverable and worth reacting to instantly — while
a symmetric AGC would pump on every gap between calls.

**The gain is frozen during RECORD.** A step mid-clip would put a discontinuity
in the waveform and make the clip useless for absolute amplitude. The step in
force is latched at trigger time and written into GUANO (`Note` plus a
namespaced `Echometer|Gain` field), so SPL can be reconstructed offline.

**Settling.** After every gain change the detector skips `GAIN_SETTLE_FRAMES`
= 2 frames while the mux's charge injection settles out of the summing node,
so a switch is never mistaken for a call.

**Persistence.** The chosen step and the AGC on/off flag are stored in NVS
under the `echometer` namespace, so a hand-picked gain survives a power cycle.

## HTTP interface

| Endpoint | Purpose |
|---|---|
| `/` | clip list, newest first, with gain shown per clip; gain and AGC controls |
| `/dl?…` | download a clip as WAV |
| `/del?…` | delete a clip |
| `/gain?i=N` | select gain step N (0–5); implicitly disables the AGC |
| `/agc?on=0\|1` | enable/disable the AGC |

The server uses 30 s send/receive timeouts so a brief link stall doesn't kill a
2 MB download.

## `main/archive/`

Older firmware variants, kept for reference (not built):

- `main_v3.c` — the unmodified v3 application, before the gain layer. Useful as
  a diff base.
- `main_sd.c` — the original SD-card / USB-CDC recorder (detect → record raw
  samples to FatFS or stream over TinyUSB CDC). Needs `sdmmc fatfs vfs` in
  CMake REQUIRES plus the `espressif/esp_tinyusb` managed component, TinyUSB
  CDC enabled in menuconfig, and a **FAT32** (not exFAT) SD card.
- `main_test.c` — minimal board bring-up test (button → sample + FFT → green
  LED on detect, ADC stats on the console).

To build one, copy it over `main/main.c` and restore the dependencies noted in
`main/CMakeLists.txt`.

---

## Lessons learned

### 1. Getting WAVs accepted by the Echo Meter iPhone app

- A bare PCM WAV is **rejected**. The app wants **GUANO metadata**
  ([guano-md.org](https://guano-md.org)): a `guan` RIFF chunk with `Timestamp`,
  `Samplerate`, `Length`, `Make`, `Model`.
- With honest `Make: DIY / Model: echometer-v4` the import fails with
  *"invalid module type"* — the app validates `Model` against known Wildlife
  Acoustics modules. Identifying as `Echo Meter Touch 2 Pro` (whose format —
  256 kHz, 16-bit, full-spectrum mono — this firmware genuinely matches) makes
  imports succeed. True provenance is kept in a GUANO `Note` field. Keep this
  in mind before sharing files anywhere that trusts the device tag.
- 256 ksps was chosen over v2's 240 ksps partly for this compatibility.
- Their filename convention `PREFIX_YYYYMMDD_HHMMSS.wav` is also worth matching
  — sessions are organised by parsed timestamp.
- Import path on iOS: Files → share sheet → *Copy to Echo Meter*. The
  `Imported Files Session.kml` the app produces is a GPS **export**, not an
  import requirement.
- iPhone file transfer without a custom app: BLE is a dead end (the S3 has no
  Bluetooth Classic; iOS has no standard BLE file-receive; nRF Connect only
  logs hex at ~10 kB/s). **SoftAP + a tiny HTTP server + Safari** is the way.

### 2. Power / brownout

Mostly fixed in v4's hardware, but the reasoning is worth keeping:

- Enabling Wi-Fi *and* octal PSRAM pushed a marginal USB supply over the edge:
  `E BOD: Brownout detector was triggered` right at Wi-Fi RF calibration (the
  biggest current spike, 300–400 mA on top of everything else).
- An inline USB "noise filter" dongle made it worse — those add series
  resistance and limit current. Straight into a PC port worked.
- **Capping TX power was tried and removed.** `CONFIG_ESP_PHY_MAX_WIFI_TX_POWER`
  = 10 dBm (plus a runtime `esp_wifi_set_max_tx_power()`) did soften the
  calibration spike, but a weaker link forces retransmits that keep the radio
  on *longer* — 2 MB clip downloads got slow and aborted mid-file. Both were
  removed; TX power runs at the default max and power is fixed on the supply
  side instead.
- Downloads are the heaviest sustained RF load the board ever sees — heavier
  than boot — so if boot is marginal, downloads fail first.
- The firmware still starts Wi-Fi ~2 s after boot (see `app_main`) so the
  boot/PSRAM inrush and the RF-cal spike don't stack. v4 adds a 470 µF
  reservoir at the module header and a battery instead of a cable.

### 3. False triggers from a floating analog input

- Touching v3's floating ADC input false-triggered the detector every time: a
  finger/contact transient is a **broadband impulse** that lifts every FFT bin
  at once, and a single-bin amplitude threshold can't tell it from a call.
- Firmware fix, both in the DETECT loop: **tonality** — the peak bin must be
  ≥ 20× the mean power of the rest of the >19 kHz band; **persistence** — 3
  consecutive frames (~26 ms) must pass before recording. Real chirps are
  narrowband and sustained; touches are flat and momentary.
- v4 fixes it in hardware too: the ADC input is driven from the TL972 through
  R17 (100 Ω) and cannot float. The two firmware tests are still worth keeping
  — they also reject wind, handling noise and machinery transients.

### 4. ESP-IDF / toolchain gotchas

- `led_strip` 2.x uses `.led_pixel_format = LED_PIXEL_FORMAT_GRB`; the
  `color_component_format` field only exists in 3.x. Match the code to the
  version in `dependencies.lock`, not to the latest docs.
- A **trailing space** typed into the menuconfig field for the custom partition
  CSV produced `CONFIG_PARTITION_TABLE_CUSTOM_FILENAME="partitions.csv "` and a
  baffling ninja error (`'…/partitions.csv ' … missing and no known rule to
  make it`). menuconfig keeps whatever you type.
- TinyUSB CDC is **not** enabled by default (`CONFIG_TINYUSB_CDC_ENABLED`) —
  the archived USB-streaming main silently needs it, plus the secondary console
  set to *None*, since USB-Serial-JTAG and TinyUSB share GPIO19/20.
- SD cards for the archived recorder must be **FAT32/MBR** (`mkfs.vfat -F 32`);
  cards over 32 GB ship exFAT, which IDF's FatFS won't mount by default.

### 5. GPIO choice is constrained by PSRAM mode

With `CONFIG_SPIRAM_MODE_OCT=y`, **GPIO35/36/37 belong to the PSRAM
controller** and cannot be used for anything else. This is why the gain-select
pins are 38/39/40 in firmware even though the v4 PCB routes two of them to
36/37 — see errata 1 in the [top-level README](../README.md#errata--read-before-ordering-the-pcb).
GPIO39/40 are MTCK/MTDO, free here only because the DevKitC-1 debugs over the
built-in USB-Serial-JTAG on GPIO19/20.

---

## Still to do

- **Ring buffer for pre-trigger audio** — the clip currently starts at the
  triggering buffer, so the calls *before* detection fired are lost. The single
  biggest capture upgrade left.
- **Adaptive trigger** — a running noise-floor estimate rather than the fixed
  `ULTRASONIC_THRESH_COUNTS`. With variable gain, a fixed count threshold means
  a *different* absolute sensitivity at each step, so this matters more now
  than it did in v3.
- **Call-shape gating** — require a swept FM component, plausible duration
  (~2–20 ms) and inter-pulse interval, to reject bush-crickets and machinery.
- **Duty cycling** for unattended overnight runs.
- **Pause the AP during the 3.84 s capture**, so no TX spike or RF pickup can
  coincide with sampling.

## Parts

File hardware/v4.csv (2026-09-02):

Designator | Qty | Value | Part# | LCSC Part # | Footprint | Datasheet
C1,C10,C26,C29 | 4 | 22uF | x | x | Capacitor_SMD:C_0805_2012Metric
C2,C4,C12,C13,C17 | 5 | 10nF | CC0805JKNPO9BN103 | C527201 | Capacitor_SMD:C_0805_2012Metric
C5,C18,C19,C24,C30 | 5 | 10uF | x | x | Capacitor_SMD:C_0805_2012Metric
C6,C7,C8,C9,C11,C20,C22,C23,C25,C27,C31 | 11 | 100nF | x | x | Capacitor_SMD:C_0805_2012Metric
C14,C15 | 2 | 27pF | x | x | Capacitor_SMD:C_0805_2012Metric
C16 | 1 | 22nF | x | x | Capacitor_SMD:C_0805_2012Metric
C21 | 1 | 2.2uF | x | x | Capacitor_SMD:C_0805_2012Metric
C28 | 1 | 470uF | x | x | Capacitor_SMD:C_Elec_10x10.2
D1 | 1 | RED |  |  | LED_SMD:LED_0805_2012Metric
D2 | 1 | GREEN |  |  | LED_SMD:LED_0805_2012Metric
D3 | 1 | D_Schottky SS34 |  |  | Diode_SMD:D_SMA
J1 | 1 | USB_B_Micro |  |  | Connector_USB:USB_Micro-B_Molex-105017-0001
J5 | 1 | Conn_01x06_Socket | x | x | Connector_PinSocket_2.54mm:PinSocket_1x06_P2.54mm_Vertical
J6 | 1 | Conn_01x02_Socket | x | x | Connector_JST:JST_PH_B2B-PH-K_1x02_P2.00mm_Vertical
J11,J12 | 2 | Conn_01x22_Socket | ZX-PM2.54-1-22PY | C7499337 | Connector_PinSocket_2.54mm:PinSocket_1x22_P2.54mm_Vertical
L1 | 1 | 4.7uH | SL0420-4R7M | C22463808 | Inductor_SMD:L_TechFuse_SL0420
R1,R2,R9 | 3 | 10K |  |  | Resistor_SMD:R_0805_2012Metric
R3,R6,R10,R12 | 4 | 1K | x | x | Resistor_SMD:R_0805_2012Metric
R4,R5,R8 | 3 | 1k |  |  | Resistor_SMD:R_0805_2012Metric
R7 | 1 | 1.2k |  |  | Resistor_SMD:R_0805_2012Metric
R11 | 1 | 31K2 | x | x | Resistor_SMD:R_0805_2012Metric
R13 | 1 | 33K | x | x | Resistor_SMD:R_0805_2012Metric
R15,R17,R18,R20 | 4 | 100 | x | x | Resistor_SMD:R_0805_2012Metric
R16 | 1 | 22 | x | x | Resistor_SMD:R_0805_2012Metric
R19 | 1 | 0R |  |  | Resistor_SMD:R_0805_2012Metric
R21 | 1 | 150K |  |  | Resistor_SMD:R_0805_2012Metric
R22 | 1 | 19.1K |  |  | Resistor_SMD:R_0805_2012Metric
R23,R25 | 2 | 22K | x | x | Resistor_SMD:R_0805_2012Metric
R24 | 1 | 6K8 | x | x | Resistor_SMD:R_0805_2012Metric
R26 | 1 | 3K6 | x | x | Resistor_SMD:R_0805_2012Metric
U1 | 1 | SPU0410LR5H-QB | x | x | wzw:XDCR_SPU0410LR5H-QB | https://www.digikey.com/en/products/detail/syntiant/SPV0142LR5H-1/13901275
U2 | 1 | TL972IDR | TL972IDR | C46127 | Package_SO:SOIC-8_3.9x4.9mm_P1.27mm
U3 | 1 | OPA838IDBVR | OPA838IDBVR | C2058363 | Package_TO_SOT_SMD:SOT-23-6 | https://www.ti.com/lit/gpn/opa838
U4 | 1 | adcs7476aimfx/nopb | ADCS7476AIMFX/NOPB | C91530 | Package_TO_SOT_SMD:SOT-23-6_Handsoldering | https://www.ti.com/cn/lit/gpn/adcs7478
U5 | 1 | TP4056 |  |  | Package_SO:SOIC-8-1EP_3.9x4.9mm_P1.27mm_EP2.29x3mm
U6 | 1 | DW01 |  |  | Package_TO_SOT_SMD:SOT-23-6
U7 | 1 | FS8205A |  |  | Package_TO_SOT_SMD:SOT-23-6
U8 | 1 | MT3608 |  |  | Package_TO_SOT_SMD:SOT-23-6 | https://www.olimex.com/Products/Breadboarding/BB-PWR-3608/resources/MT3608.pdf
U9 | 1 | 74HC4053D_653 |  |  | SO16_SOT109-1_NEX | 74HC4053D_653
U10 | 1 | TPS74801DRCR | TPS74801DRCR | C105263 | Package_SON:VSON-10-1EP_3x3mm_P0.5mm_EP1.65x2.4mm

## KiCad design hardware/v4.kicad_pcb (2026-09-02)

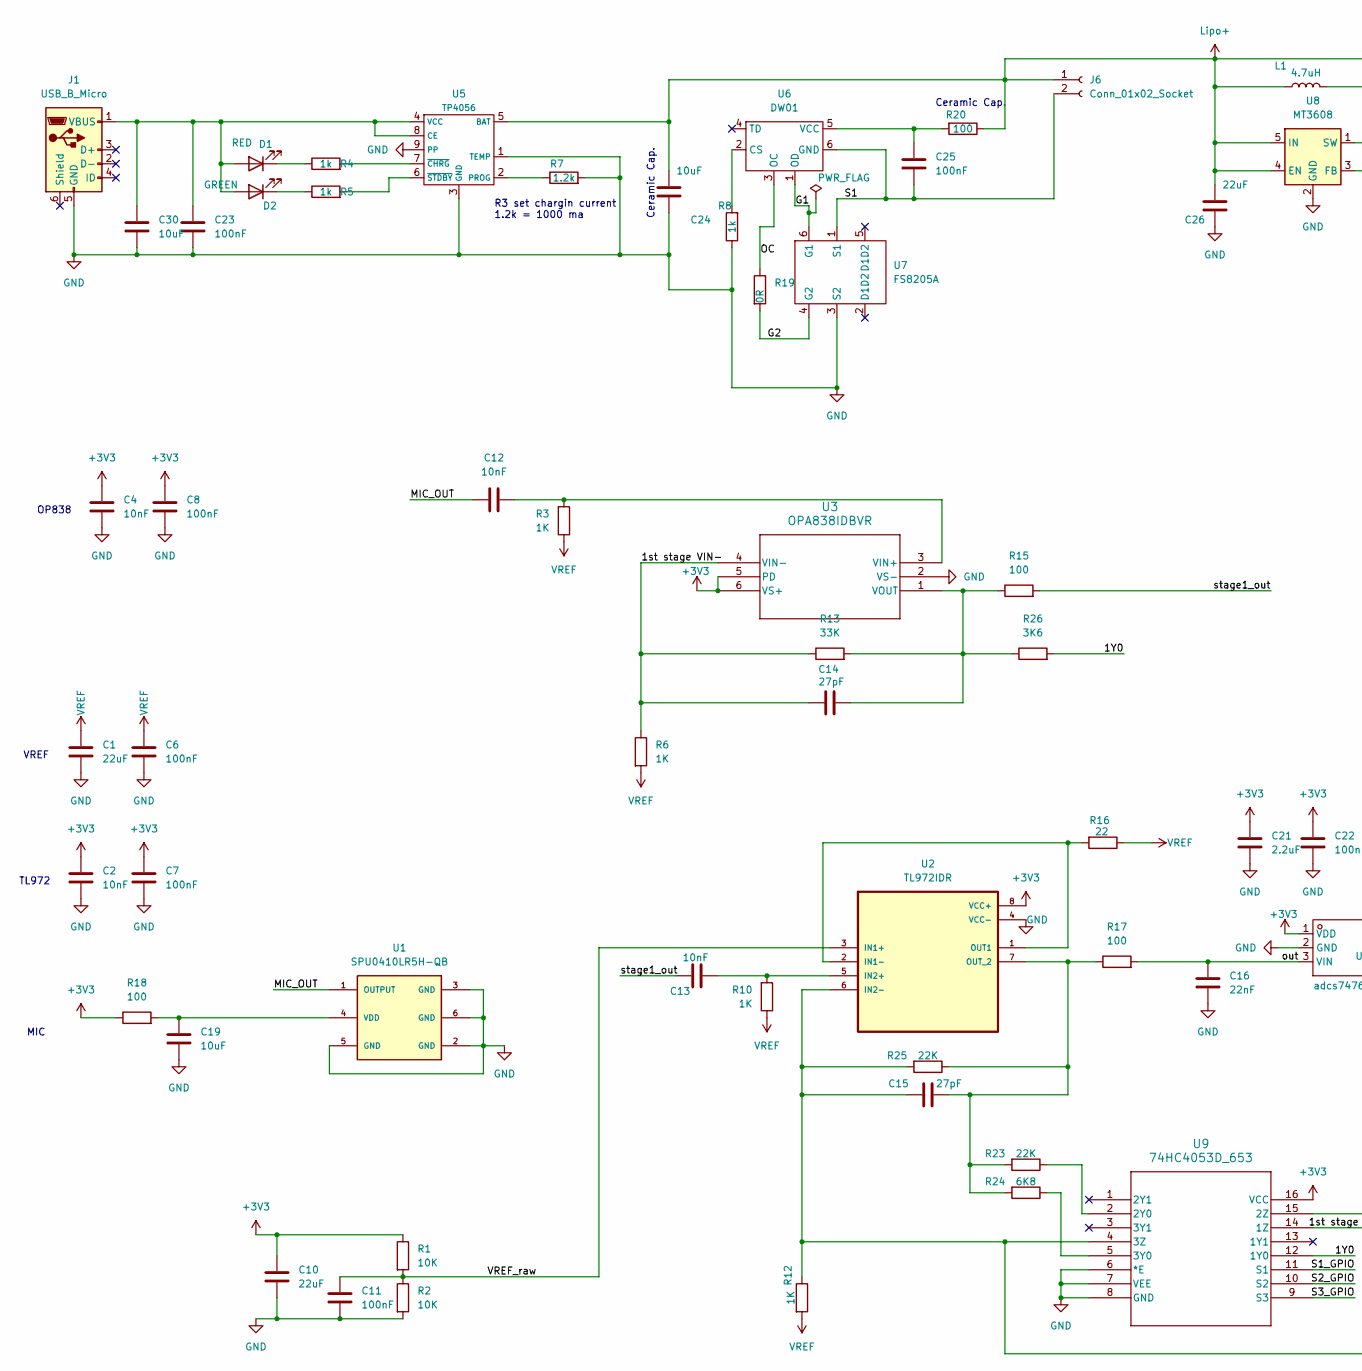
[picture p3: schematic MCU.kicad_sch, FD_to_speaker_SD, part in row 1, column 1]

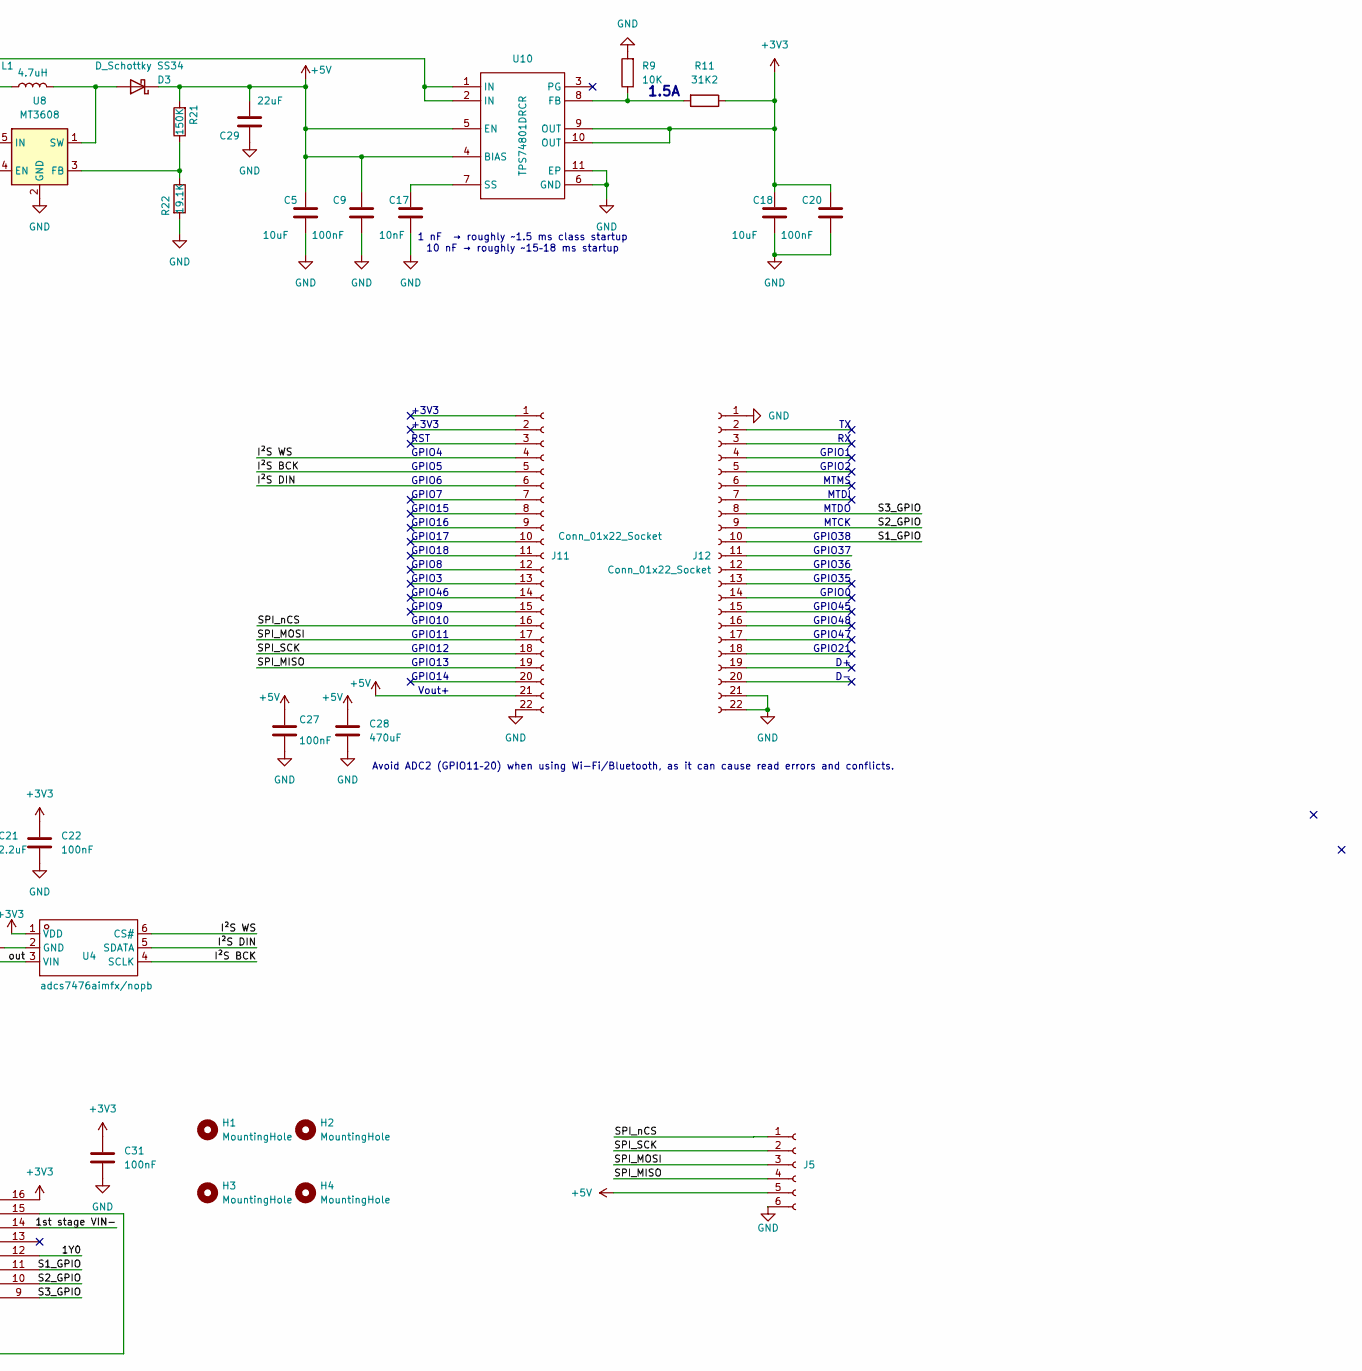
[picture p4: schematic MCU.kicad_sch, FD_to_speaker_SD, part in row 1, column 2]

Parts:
C1, C10: 22uF; C_0805_2012Metric; Part# x; LCSC Part # x
C2, C4, C12, C13, C17: 10nF; C_0805_2012Metric; Part# CC0805JKNPO9BN103; LCSC Part # C527201
C5, C18: 10uF; C_0805_2012Metric; Part# x; LCSC Part # x
C6, C7, C8, C9, C11, C20, C22, C27, C31: 100nF; C_0805_2012Metric; Part# x; LCSC Part # x
C14, C15: 27pF; C_0805_2012Metric; Part# x; LCSC Part # x
C16: 22nF; C_0805_2012Metric; Part# CC0805JKNPO9BN103; LCSC Part # C527201
C19: 10uF; C_0805_2012Metric; Part# CC0805JKNPO9BN103; LCSC Part # C527201
C21: 2.2uF; C_0805_2012Metric; Part# x; LCSC Part # x
C23, C25: 100nF; C_0805_2012Metric
C24, C30: 10uF; C_0805_2012Metric
C26, C29: 22uF; C_0805_2012Metric
C28: 470uF; C_Elec_10x10.2; Part# x; LCSC Part # x
D1: RED; LED_0805_2012Metric
D2: GREEN; LED_0805_2012Metric
D3: D_Schottky SS34; D_SMA
H1, H2, H3, H4: MountingHole; MountingHole_2.1mm; Part# x; LCSC Part # x
J1: USB_B_Micro; USB_Micro-B_Molex-105017-0001
J5: Conn_01x06_Socket; PinSocket_1x06_P2.54mm_Vertical; Part# x; LCSC Part # x
J6: Conn_01x02_Socket; JST_PH_B2B-PH-K_1x02_P2.00mm_Vertical; Part# x; LCSC Part # x
J11, J12: Conn_01x22_Socket; PinSocket_1x22_P2.54mm_Vertical; Part# ZX-PM2.54-1-22PY; LCSC Part # C7499337
L1: 4.7uH; L_TechFuse_SL0420; Part# SL0420-4R7M; LCSC Part # C22463808
R1, R2, R9: 10K; R_0805_2012Metric
R3, R6, R10, R12: 1K; R_0805_2012Metric; Part# x; LCSC Part # x
R4, R5, R8: 1k; R_0805_2012Metric
R7: 1.2k; R_0805_2012Metric
R11: 31K2; R_0805_2012Metric; Part# x; LCSC Part # x
R13: 33K; R_0805_2012Metric; Part# RC0805FR-0724KL; LCSC Part # C137562
R15, R17, R18: 100; R_0805_2012Metric; Part# x; LCSC Part # x
R16: 22; R_0805_2012Metric; Part# x; LCSC Part # x
R19: 0R; R_0805_2012Metric
R20: 100; R_0805_2012Metric
R21: 150K; R_0805_2012Metric
R22: 19.1K; R_0805_2012Metric
R23: 22K; R_0805_2012Metric
R24: 6K8; R_0805_2012Metric; Part# RC0805FR-0724KL; LCSC Part # C137562
R25: 22K; R_0805_2012Metric; Part# RC0805FR-0724KL; LCSC Part # C137562
R26: 3K6; R_0805_2012Metric; Part# RC0805FR-0724KL; LCSC Part # C137562
U1: SPU0410LR5H-QB; XDCR_SPU0410LR5H-QB; Part# x; LCSC Part # x
U2: TL972IDR; SOIC-8_3.9x4.9mm_P1.27mm; Part# TL972IDR; LCSC Part # C46127
U3: OPA838IDBVR; SOT-23-6; Part# OPA838IDBVR; LCSC Part # C2058363
U4: adcs7476aimfx/nopb; SOT-23-6_Handsoldering; VOLTAGE - SUPPLY 2.7V~5.25V; VOLTAGE REFERENCE 内置; MANUFACTURERPART ADCS7476AIMFX/NOPB; LCSC PART NAME 1 Msps、12bit 、10bit 和8bit A/D转换器
U5: TP4056; SOIC-8-1EP_3.9x4.9mm_P1.27mm_EP2.29x3mm
U6: DW01; SOT-23-6
U7: FS8205A; SOT-23-6
U8: MT3608; SOT-23-6
U9: 74HC4053D_653; SO16_SOT109-1_NEX
U10: TPS74801DRCR; VSON-10-1EP_3x3mm_P0.5mm_EP1.65x2.4mm; Part# TPS74801DRCR; LCSC Part # C105263

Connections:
+3V3: C2.1, C4.1, C7.1, C8.1, C10.1, C18.1, C20.1, C21.1, C22.1, C31.1, R1.1, R11.1, R18.1, U2.8 (VCC+), U3.5 (PD), U3.6 (VS+), U4.1 (VDD), U9.16 (VCC), U10.9 (OUT), U10.10 (OUT)
+5V: C5.1, C9.1, C27.1, C28.1, C29.1, D3.1 (K), J5.5, J11.21, R21.2, U10.4 (BIAS), U10.5 (EN)
/MCU_SD/1st stage VIN-: C14.2, R6.1, R13.1, U3.4 (VIN-), U9.14 (1Z)
/MCU_SD/G1: U6.1 (OD), U7.6 (G1)
/MCU_SD/G2: R19.2, U7.4 (G2)
/MCU_SD/IY0: R26.2, U9.12 (1Y0)
/MCU_SD/I²S BCK: J11.5, U4.4 (SCLK)
/MCU_SD/I²S DIN: J11.6, U4.5 (SDATA)
/MCU_SD/I²S WS: J11.4, U4.6 (CS#)
/MCU_SD/MIC_OUT: C12.2, U1.1 (OUTPUT)
/MCU_SD/OC: R19.1, U6.3 (OC)
/MCU_SD/S1: C25.2, J6.2, U6.6 (GND), U7.1 (S1)
/MCU_SD/S1_GPIO: J12.10, U9.11 (S1)
/MCU_SD/S2_GPIO: J12.9, U9.10 (S2)
/MCU_SD/S3_GPIO: J12.8, U9.9 (S3)
/MCU_SD/SPI_MISO: J5.4, J11.19
/MCU_SD/SPI_MOSI: J5.3, J11.17
/MCU_SD/SPI_SCK: J5.2, J11.18
/MCU_SD/SPI_nCS: J5.1, J11.16
/MCU_SD/VREF_raw: C11.1, R1.2, R2.1, U2.3 (IN1+)
/MCU_SD/out: C16.1, R17.2, U4.3 (VIN)
/MCU_SD/stage1_out: C13.2, R15.2
GND: C1.2, C2.2, C4.2, C5.2, C6.2, C7.2, C8.2, C9.2, C10.2, C11.2, C16.2, C17.2, C18.2, C19.2, C20.2, C21.2, C22.2, C23.2, C24.2, C26.2, C27.2, C28.2, C29.2, C30.2, C31.2, J1.5 (GND), J5.6, J11.22, J12.1, J12.21, J12.22, R2.2, R7.2, R8.1, R9.2, R22.2, U1.2 (GND), U1.3 (GND), U1.5 (GND), U1.6 (GND), U2.4 (VCC-), U3.2 (VS-), U4.2 (GND), U5.1 (TEMP), U5.3 (GND), U5.9 (PP), U7.3 (S2), U8.2 (GND), U9.6 (*E), U9.7 (VEE), U9.8 (GND), U10.6 (GND), U10.11 (EP)
Lipo+: C24.1, C26.1, J6.1, L1.1, R20.1, U5.5 (BAT), U8.4 (EN), U8.5 (IN), U10.1 (IN), U10.2 (IN)
unnamed: C23.1, C30.1, D1.2 (A), D2.2 (A), J1.1 (VBUS), U5.4 (VCC), U5.8 (CE)
unnamed: D1.1 (K), R4.1
unnamed: D2.1 (K), R5.1
unnamed: D3.2 (A), L1.2, U8.1 (SW)
unnamed: C19.1, R18.2, U1.4 (VDD)
unnamed: R16.2, U2.1 (OUT1), U2.2 (IN1-)
unnamed: C13.1, R10.2, U2.5 (IN2+)
unnamed: C15.2, R12.1, R25.2, U2.6 (IN2-), U9.4 (3Z), U9.15 (2Z)
unnamed: C15.1, R17.1, R23.2, R24.2, R25.1, U2.7 (OUT_2)
unnamed: C12.1, R3.2, U3.3 (VIN+)
unnamed: C14.1, R13.2, R15.1, R26.1, U3.1 (VOUT)
unnamed: R7.1, U5.2 (PROG)
unnamed: R4.2, U5.7 (~CHRG)
unnamed: R5.2, U5.6 (~STDBY)
unnamed: R8.2, U6.2 (CS)
unnamed: C25.1, R20.2, U6.5 (VCC)
unnamed: R21.1, R22.1, U8.3 (FB)
unnamed: R23.1, U9.2 (2Y0)
unnamed: R24.1, U9.5 (3Y0)
unnamed: R9.1, R11.2, U10.8 (FB)
unnamed: C17.1, U10.7 (SS)
VREF: C1.1, C6.1, R3.1, R6.2, R10.1, R12.2, R16.1

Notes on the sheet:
GPIO47
GPIO5
+3V3
MTDO
GPIO2
Avoid ADC2 (GPIO11–20) when using Wi-Fi/Bluetooth, as it can cause read errors and conflicts.
MTCK
VREF
GPIO4
Ceramic Cap.
GPIO35
GPIO17
RST
GPIO6
GPIO0
GPIO10
Vout+
GPIO37
1 nF → roughly ~1.5 ms class startup 10 nF → roughly ~15–18 ms startup
GPIO9
GPIO46
GPIO11
GPIO48
TL972
MIC
MTDI
GPIO7
GPIO1
GPIO18
MTMS
GPIO13
1.5A
GPIO15
GPIO16
R3 set chargin current 1.2k = 1000 ma
GPIO12
GPIO8
GPIO36
GPIO45
GPIO14

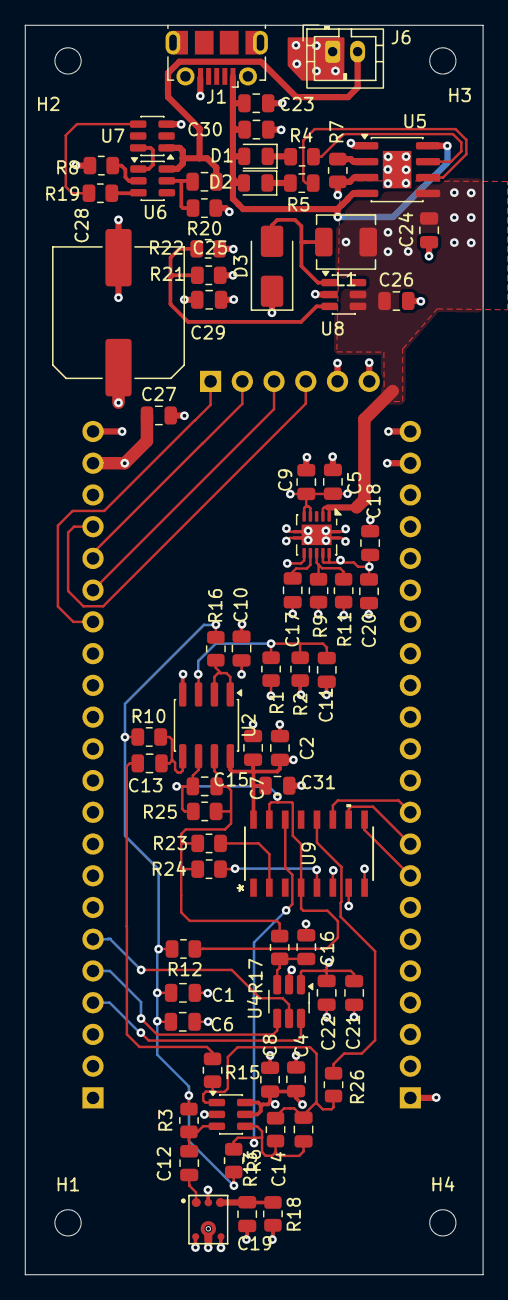
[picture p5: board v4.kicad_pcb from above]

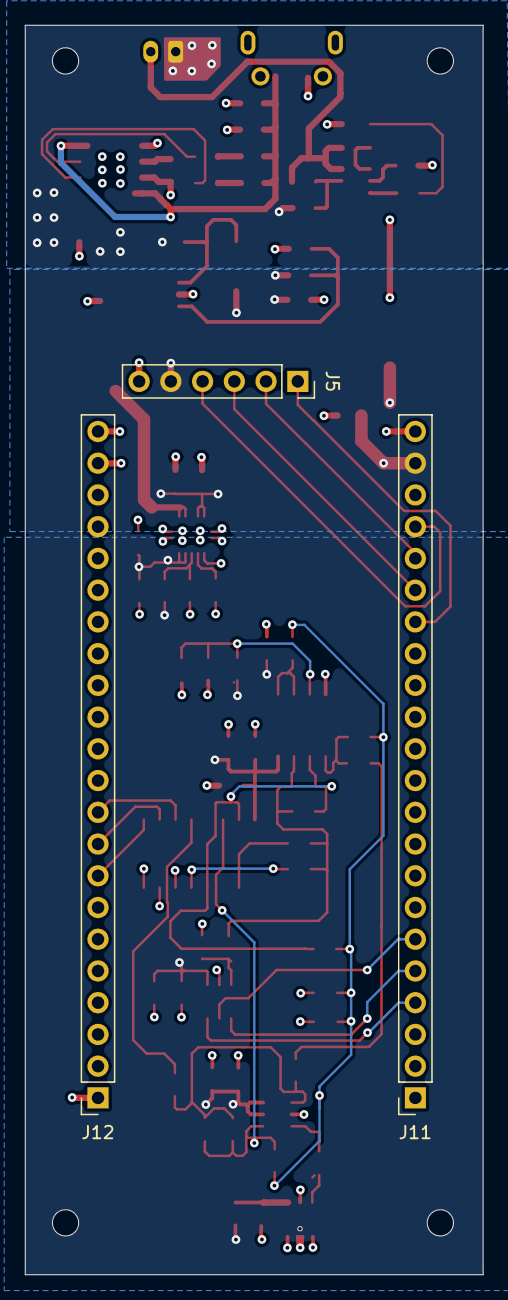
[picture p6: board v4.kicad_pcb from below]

Board: 4 copper layers, 36.6 x 100.0 mm, 78 parts (3 on the bottom side), 46 nets.

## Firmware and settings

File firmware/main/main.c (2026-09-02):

/**
 ******************************************************************************
 * main.c — ultrasonic chirp catcher, v4 (ESP32-S3)
 *
 * v4 adds SWITCHED ANALOG GAIN on top of the v3 firmware. A 74HC4053 analog
 * mux picks the feedback resistors of both amplifier stages, giving six gain
 * steps from 22x to 782x (26.9 .. 57.9 dB, ~6 dB apart). The gain is settable
 * from the web page, or tracked automatically by an AGC with fast attack and
 * slow decay. See README.md for the resistor network and the SPL budget.
 *
 * States
 *   IDLE   : LED off. Wi-Fi SoftAP + HTTP server up; captured chirps are
 *            listed at http://192.168.4.1 and downloadable as WAV in Safari.
 *   DETECT : after a BOOT-button press — ADC sampling + FFT, LED off while
 *            armed, flashing green while ultrasonic is being detected.
 *            Press again to cancel back to IDLE.
 *   RECORD : detection persists (see filters below) — clip streams into a
 *            PSRAM slot, then back to IDLE. GAIN IS FROZEN for the whole clip.
 *
 * Clips live in PSRAM only (lost at power-off): 3.84 s @ 256 ksps 16-bit =
 * ~1.97 MB each; an 8 MB (N16R8) module fits 4 slots, oldest is overwritten.
 * WAVs carry a GUANO metadata chunk and Wildlife-Acoustics-style filenames
 * (CHIRP_YYYYMMDD_HHMMSS.wav) so the Echo Meter iPhone app accepts them.
 * No RTC on board: the clock is seeded from firmware build time at boot.
 *
 * Wiring
 *   ADC  : ADCS7476 — CS<-GPIO4 (I2S WS), SCLK<-GPIO5 (I2S BCK), SDATA->GPIO6
 *   GAIN : 74HC4053 — S1<-GPIO38, S2<-GPIO39, S3<-GPIO40
 *   RGB  : GPIO48 (WS2812)   BTN : GPIO0 (BOOT, active-low)
 *
 *   NOTE: GPIO35/36/37 are NOT usable on an N16R8 module — they belong to the
 *   octal PSRAM bus. The gain lines must stay clear of them.
 ******************************************************************************
 */
#include <stdio.h>
#include <stdlib.h>
#include <string.h>
#include <math.h>
#include <time.h>
#include <sys/time.h>

#include "freertos/FreeRTOS.h"
#include "freertos/task.h"

#include "esp_log.h"
#include "esp_err.h"
#include "esp_timer.h"
#include "esp_heap_caps.h"

#include "driver/gpio.h"
#include "driver/i2s_std.h"

#include "nvs_flash.h"
#include "nvs.h"
#include "esp_netif.h"
#include "esp_event.h"
#include "esp_wifi.h"
#include "esp_http_server.h"

#include "led_strip.h"
#include "esp_dsp.h"

static const char *TAG = "chirp";

/* ── Pin map ─────────────────────────────────────────────────────────────── */
#define PIN_ADC_CS      GPIO_NUM_4
#define PIN_ADC_CLK     GPIO_NUM_5
#define PIN_ADC_SDATA   GPIO_NUM_6
#define ADC_I2S_PORT    I2S_NUM_0
#define PIN_RGB         GPIO_NUM_48
#define PIN_BTN         GPIO_NUM_0

/* 74HC4053 select lines. Keep off GPIO35/36/37 (octal PSRAM on N16R8). */
#define PIN_GAIN_S1     GPIO_NUM_38
#define PIN_GAIN_S2     GPIO_NUM_39
#define PIN_GAIN_S3     GPIO_NUM_40

/* ── Wi-Fi AP ────────────────────────────────────────────────────────────── */
#define AP_SSID         "echometer"        /* open network, no password */
#define AP_CHANNEL      1
#define AP_MAX_CONN     2

/* ── Sampling / FFT ──────────────────────────────────────────────────────── */
#define SAMPLE_RATE_HZ      256000U
#define FFT_SIZE            2048U
#define ADC_SAMPLE_SHIFT    0

#define ULTRASONIC_BIN_MIN  ((uint32_t)((19000UL * FFT_SIZE + SAMPLE_RATE_HZ - 1U) \
                              / SAMPLE_RATE_HZ))   /* 152 */
#define ULTRASONIC_THRESH_COUNTS  50.0f
#define ULTRASONIC_THRESH_SQ      ((ULTRASONIC_THRESH_COUNTS * (FFT_SIZE / 2.0f)) \
                                 * (ULTRASONIC_THRESH_COUNTS * (FFT_SIZE / 2.0f)))

/* False-trigger rejection. A finger/contact transient is a broadband impulse:
 * it lifts the whole spectrum for a frame or two. A real chirp is narrowband
 * and sustained. So require both:
 *  - tonality: peak bin power >= TONALITY_MIN x the average power of the rest
 *    of the >19 kHz band (a flat broadband burst fails this), and
 *  - persistence: DETECT_CONSEC consecutive FFT frames (~8 ms each) must
 *    pass before recording starts. Lower to 1-2 if hunting very short clicks. */
#define CHIRP_TONALITY_MIN  20.0f
#define DETECT_CONSEC       3U

/* ── Variable gain (74HC4053) ────────────────────────────────────────────────
 * Stage 1 (OPA838): Rg = R6 = 1k, Rf = R13 = 33k, and R26 = 3k6 switched in
 *                   parallel by mux switch 1  ->  gain 34 or 4.25
 * Stage 2 (TL972) : Rg = R12 = 1k, Rf = R25 = 22k permanent, with R23 = 22k
 *                   (switch 2) and R24 = 6k8 (switch 3) switchable in parallel
 *                   ->  gain 23 / 12 / 6.19 / 5.20
 *
 * 4053 truth table: Sn LOW selects Yn0 = the resistor is CONNECTED = parallel
 * combination = LOWER gain. Sn HIGH selects Yn1, which is a no-connect.
 * R13 and R25 are permanent, so the loop is never open — and all-LOW (the
 * state the GPIOs sit in at reset) is minimum gain, which cannot clip.
 *
 * clip_spl is the input level at which the TL972 output hits its rail, for the
 * SPU0410 at -38 dBV/Pa and ~1.45 V peak of available swing. Use it to pick a
 * step for the environment; the AGC below does it from the samples instead. */
typedef struct {
    uint8_t  s1, s2, s3;    /* 4053 select levels                            */
    uint16_t gain;          /* total voltage gain, stage 1 x stage 2         */
    uint8_t  clip_spl;      /* approx. input that clips, dB SPL re 20 uPa    */
} gain_step_t;

static const gain_step_t GAIN_STEPS[] = {
    /* S1 S2 S3   gain  clip                                                 */
    {  0, 0, 0,     22, 105 },   /* cave / roost, bats at arm's length       */
    {  0, 0, 1,     51,  98 },
    {  0, 1, 1,     98,  92 },   /* general close work                       */
    {  1, 1, 0,    210,  86 },
    {  1, 0, 1,    408,  80 },
    {  1, 1, 1,    782,  74 },   /* max — distant passes, ~30 m              */
};
#define GAIN_NSTEPS   (sizeof(GAIN_STEPS) / sizeof(GAIN_STEPS[0]))
#define GAIN_DEFAULT  3U        /* 210x — a sane cold-start compromise       */

/* AGC. Asymmetric on purpose: drop the gain the instant a frame gets close to
 * full scale (a clipped call is unrecoverable — the clipping happens in the
 * analog domain, before the ADC), but only raise it after a sustained quiet
 * spell, otherwise the gain pumps on every gap between calls. */
#define AGC_FULLSCALE      2048.0f    /* 12-bit, centred                     */
#define AGC_ATTACK_LEVEL   (0.90f * AGC_FULLSCALE)
#define AGC_DECAY_LEVEL    (0.10f * AGC_FULLSCALE)
#define AGC_DECAY_FRAMES   120U       /* ~1 s of quiet before stepping up    */
#define GAIN_SETTLE_FRAMES 2U         /* frames to ignore after a gain change */

static volatile uint8_t  g_gain_idx = GAIN_DEFAULT;
static volatile bool     g_agc_on   = true;
static volatile uint16_t g_peak     = 0;   /* peak of the last frame, 0..2048 */

/* ── Clip storage ────────────────────────────────────────────────────────── */
/* 480 FFT buffers = 983 040 samples = 3.84 s @ 256 ksps = 1.97 MB per clip,
 * chosen so FOUR slots (7.5 MiB) fit in 8 MB PSRAM with headroom to spare. */
#define CLIP_BUFS           480U
#define CLIP_SAMPLES        (CLIP_BUFS * FFT_SIZE)
#define CLIP_BYTES          (CLIP_SAMPLES * sizeof(int16_t))
#define MAX_CLIP_SLOTS      8U
#define SPIRAM_RESERVE      (512U * 1024U) /* leave headroom for Wi-Fi/heap    */

#define BTN_DEBOUNCE_US     50000
#define LED_BRIGHTNESS      40

typedef enum { ST_IDLE, ST_DETECT, ST_RECORD } AppState;
typedef enum { LED_OFF, LED_GREEN_FLASH, LED_BLUE_FLASH, LED_ERR } LedMode;

typedef struct {
    int16_t      *data;                    /* CLIP_SAMPLES, in PSRAM          */
    volatile bool ready;                   /* false while being (re)written   */
    uint32_t      seq;                     /* global chirp number, 1..        */
    time_t        cap_time;                /* capture wall time               */
    uint16_t      gain;                    /* gain in force for the whole clip */
} clip_slot_t;

static clip_slot_t g_slots[MAX_CLIP_SLOTS];
static uint32_t    g_num_slots = 0;
static uint32_t    g_next_seq  = 1;

static volatile AppState g_state     = ST_IDLE;
static volatile LedMode  g_led_mode  = LED_OFF;
static volatile uint8_t  g_btn_event = 0;

static uint16_t sample_buf[FFT_SIZE];
static float    fft_buf[FFT_SIZE * 2];
static int16_t  i2s_raw[FFT_SIZE * 2];

static i2s_chan_handle_t  i2s_rx    = NULL;
static led_strip_handle_t led_strip = NULL;

/* ── 44-byte canonical WAV header (PCM mono 16-bit) ──────────────────────── */
typedef struct __attribute__((packed)) {
    char     riff[4];   uint32_t riff_size; char wave[4];
    char     fmt[4];    uint32_t fmt_size;
    uint16_t audio_fmt; uint16_t channels;
    uint32_t rate;      uint32_t byte_rate;
    uint16_t block_align; uint16_t bits;
    char     data[4];   uint32_t data_size;
} wav_header_t;

static void wav_header_fill(wav_header_t *h, uint32_t rate, uint32_t data_bytes)
{
    memcpy(h->riff, "RIFF", 4);  h->riff_size = 36 + data_bytes;
    memcpy(h->wave, "WAVE", 4);
    memcpy(h->fmt,  "fmt ", 4);  h->fmt_size = 16;
    h->audio_fmt = 1;  h->channels = 1;
    h->rate = rate;    h->byte_rate = rate * 2;
    h->block_align = 2; h->bits = 16;
    memcpy(h->data, "data", 4);  h->data_size = data_bytes;
}

/* No RTC/NTP on this board: seed the system clock from firmware build time
 * so capture timestamps and filenames are plausible and monotonic. */
static void clock_init(void)
{
    static const char mon[] = "JanFebMarAprMayJunJulAugSepOctNovDec";
    char m[4] = { __DATE__[0], __DATE__[1], __DATE__[2], '\0' };
    struct tm tm = {
        .tm_mon  = (int)((strstr(mon, m) - mon) / 3),
        .tm_mday = atoi(__DATE__ + 4),
        .tm_year = atoi(__DATE__ + 7) - 1900,
        .tm_hour = atoi(__TIME__),
        .tm_min  = atoi(__TIME__ + 3),
        .tm_sec  = atoi(__TIME__ + 6),
    };
    struct timeval tv = { .tv_sec = mktime(&tm) };
    settimeofday(&tv, NULL);
}

/* Wildlife-Acoustics-style name: CHIRP_YYYYMMDD_HHMMSS.wav */
static void clip_filename(const clip_slot_t *s, char *out, size_t n)
{
    struct tm tm;
    localtime_r(&s->cap_time, &tm);
    snprintf(out, n, "CHIRP_%04d%02d%02d_%02d%02d%02d.wav",
             tm.tm_year + 1900, tm.tm_mon + 1, tm.tm_mday,
             tm.tm_hour, tm.tm_min, tm.tm_sec);
}

/* GUANO metadata (https://guano-md.org) — Wildlife Acoustics apps use this
 * to recognise bat recordings. Returned length is always even (RIFF rule).
 *
 * The analog gain in force is recorded twice: in the free-text Note, and as a
 * namespaced "Echometer|Gain" field (GUANO readers must ignore namespaces they
 * don't know). Without it the absolute SPL of a clip can't be reconstructed
 * offline, because the same waveform amplitude means 31 dB more sound at 22x
 * than at 782x. If the Echo Meter import ever starts failing, drop the
 * namespaced line first — the Note is the safer of the two. */
static int guano_build(const clip_slot_t *s, char *out, size_t n)
{
    struct tm tm;
    localtime_r(&s->cap_time, &tm);
    /* The Echo Meter app refuses imports whose Model isn't a known WA module
     * ("invalid module type"), so identify as the module whose format we
     * match (256 kHz 16-bit full-spectrum). Real provenance is in Note. */
    int len = snprintf(out, n,
        "GUANO|Version: 1.0\n"
        "Make: Wildlife Acoustics, Inc.\n"
        "Model: Echo Meter Touch 2 Pro\n"
        "Note: recorded by DIY echometer-v4, analog gain %ux\n"
        "Samplerate: %u\n"
        "Length: %.2f\n"
        "Timestamp: %04d-%02d-%02dT%02d:%02d:%02d\n"
        "Echometer|Gain: %u",
        (unsigned)s->gain,
        (unsigned)SAMPLE_RATE_HZ, (float)CLIP_SAMPLES / SAMPLE_RATE_HZ,
        tm.tm_year + 1900, tm.tm_mon + 1, tm.tm_mday,
        tm.tm_hour, tm.tm_min, tm.tm_sec,
        (unsigned)s->gain);
    if (len & 1) out[len++] = '\n';    /* pad to even length */
    out[len] = '\0';
    return len;
}

/* ── Variable gain ───────────────────────────────────────────────────────── */
static void gain_apply(uint8_t idx)
{
    if (idx >= GAIN_NSTEPS) idx = GAIN_NSTEPS - 1U;
    const gain_step_t *s = &GAIN_STEPS[idx];
    gpio_set_level(PIN_GAIN_S1, s->s1);
    gpio_set_level(PIN_GAIN_S2, s->s2);
    gpio_set_level(PIN_GAIN_S3, s->s3);
    g_gain_idx = idx;
}

/* Persist only deliberate (web) changes, not every AGC step — the AGC can move
 * many times a minute and NVS is flash. */
static void gain_save(void)
{
    nvs_handle_t h;
    if (nvs_open("echometer", NVS_READWRITE, &h) != ESP_OK) return;
    nvs_set_u8(h, "gain", g_gain_idx);
    nvs_set_u8(h, "agc",  g_agc_on ? 1 : 0);
    nvs_commit(h);
    nvs_close(h);
}

static void gain_init(void)
{
    gpio_config_t io = {
        .pin_bit_mask = (1ULL << PIN_GAIN_S1) | (1ULL << PIN_GAIN_S2) |
                        (1ULL << PIN_GAIN_S3),
        .mode         = GPIO_MODE_OUTPUT,
        .pull_up_en   = GPIO_PULLUP_DISABLE,
        .pull_down_en = GPIO_PULLDOWN_ENABLE,   /* min gain if ever floated  */
        .intr_type    = GPIO_INTR_DISABLE,
    };
    ESP_ERROR_CHECK(gpio_config(&io));

    uint8_t idx = GAIN_DEFAULT, agc = 1;
    nvs_handle_t h;
    if (nvs_open("echometer", NVS_READONLY, &h) == ESP_OK) {
        uint8_t v;
        if (nvs_get_u8(h, "gain", &v) == ESP_OK && v < GAIN_NSTEPS) idx = v;
        if (nvs_get_u8(h, "agc",  &v) == ESP_OK)                    agc = v;
        nvs_close(h);
    }
    g_agc_on = agc ? true : false;
    gain_apply(idx);
    ESP_LOGI(TAG, "gain %ux (step %u/%u), AGC %s",
             (unsigned)GAIN_STEPS[idx].gain, (unsigned)idx,
             (unsigned)GAIN_NSTEPS - 1U, g_agc_on ? "on" : "off");
}

/* Returns true if the gain moved, so the caller can skip a frame or two while
 * the mux charge injection settles out of the summing node. */
static bool agc_update(uint16_t peak)
{
    static uint32_t hold = AGC_DECAY_FRAMES;

    if (!g_agc_on) return false;

    if (peak > AGC_ATTACK_LEVEL) {          /* clipping imminent — act NOW    */
        hold = AGC_DECAY_FRAMES;
        if (g_gain_idx > 0) {
            gain_apply(g_gain_idx - 1U);
            ESP_LOGI(TAG, "AGC down -> %ux (peak %u)",
                     (unsigned)GAIN_STEPS[g_gain_idx].gain, (unsigned)peak);
            return true;
        }
    } else if (peak < AGC_DECAY_LEVEL) {    /* lots of headroom — creep up    */
        if (hold > 0) { hold--; }
        else {
            hold = AGC_DECAY_FRAMES;
            if (g_gain_idx + 1U < GAIN_NSTEPS) {
                gain_apply(g_gain_idx + 1U);
                ESP_LOGI(TAG, "AGC up -> %ux (peak %u)",
                         (unsigned)GAIN_STEPS[g_gain_idx].gain, (unsigned)peak);
                return true;
            }
        }
    } else {
        hold = AGC_DECAY_FRAMES;            /* in the sweet spot — sit still  */
    }
    return false;
}

/* ── LED task ────────────────────────────────────────────────────────────────
 * The WS2812 is driven over RMT (GPIO48); every refresh is a burst of pulses
 * that can couple into the high-gain analog front end. So in LED_OFF we touch
 * the strip exactly ONCE (on entry) and then stay completely idle — this is
 * what keeps the LED silent through the RECORD window, where g_led_mode is set
 * to LED_OFF, so no periodic clicks are injected into the clip. Only the flash
 * modes refresh repeatedly, and those never overlap the sampling of a clip. */
static void led_task(void *arg)
{
    (void)arg;
    LedMode last = LED_ERR;      /* != LED_OFF, so the first OFF clears once */
    bool on = false;
    for (;;) {
        LedMode m = g_led_mode;
        if (m == LED_OFF) {
            if (m != last) { led_strip_clear(led_strip); on = false; }
            last = m;
            vTaskDelay(pdMS_TO_TICKS(30));
            continue;
        }
        /* LED_GREEN_FLASH / LED_BLUE_FLASH / LED_ERR — blink */
        on = !on;
        if (on) {
            uint8_t r = (m == LED_ERR)         ? LED_BRIGHTNESS : 0;
            uint8_t g = (m == LED_GREEN_FLASH) ? LED_BRIGHTNESS : 0;
            uint8_t b = (m == LED_BLUE_FLASH)  ? LED_BRIGHTNESS : 0;
            led_strip_set_pixel(led_strip, 0, r, g, b);
            led_strip_refresh(led_strip);
        } else {
            led_strip_clear(led_strip);
        }
        last = m;
        vTaskDelay(pdMS_TO_TICKS(m == LED_ERR ? 150 : 100));
    }
}

/* ── Button ISR ──────────────────────────────────────────────────────────── */
static void IRAM_ATTR btn_isr(void *arg)
{
    (void)arg;
    static int64_t last_us = 0;
    int64_t now = esp_timer_get_time();
    if (now - last_us < BTN_DEBOUNCE_US) return;
    last_us = now;
    g_btn_event = 1;
}

/* ── Peripheral init ─────────────────────────────────────────────────────── */
static void adc_i2s_init(void)
{
    i2s_chan_config_t chan_cfg = I2S_CHANNEL_DEFAULT_CONFIG(ADC_I2S_PORT, I2S_ROLE_MASTER);
    chan_cfg.dma_desc_num  = 8;            /* ~34 ms of DMA buffering          */
    chan_cfg.dma_frame_num = 1023;
    ESP_ERROR_CHECK(i2s_new_channel(&chan_cfg, NULL, &i2s_rx));

    i2s_std_config_t std_cfg = {
        .clk_cfg  = I2S_STD_CLK_DEFAULT_CONFIG(SAMPLE_RATE_HZ),
        .slot_cfg = I2S_STD_PHILIPS_SLOT_DEFAULT_CONFIG(I2S_DATA_BIT_WIDTH_16BIT,
                                                        I2S_SLOT_MODE_STEREO),
        .gpio_cfg = {
            .mclk = I2S_GPIO_UNUSED,
            .bclk = PIN_ADC_CLK,
            .ws   = PIN_ADC_CS,
            .dout = I2S_GPIO_UNUSED,
            .din  = PIN_ADC_SDATA,
            .invert_flags = { .mclk_inv = false, .bclk_inv = false, .ws_inv = false },
        },
    };
    ESP_ERROR_CHECK(i2s_channel_init_std_mode(i2s_rx, &std_cfg));
    ESP_ERROR_CHECK(i2s_channel_enable(i2s_rx));
}

static void led_init(void)
{
    led_strip_config_t strip_cfg = {
        .strip_gpio_num = PIN_RGB,
        .max_leds       = 1,
        .led_model      = LED_MODEL_WS2812,
        .led_pixel_format = LED_PIXEL_FORMAT_GRB,
        .flags = { .invert_out = false },
    };
    led_strip_rmt_config_t rmt_cfg = {
        .clk_src       = RMT_CLK_SRC_DEFAULT,
        .resolution_hz = 10 * 1000 * 1000,
        .flags         = { .with_dma = false },
    };
    ESP_ERROR_CHECK(led_strip_new_rmt_device(&strip_cfg, &rmt_cfg, &led_strip));
    led_strip_clear(led_strip);
}

static void btn_init(void)
{
    gpio_config_t io = {
        .pin_bit_mask = 1ULL << PIN_BTN,
        .mode         = GPIO_MODE_INPUT,
        .pull_up_en   = GPIO_PULLUP_ENABLE,
        .pull_down_en = GPIO_PULLDOWN_DISABLE,
        .intr_type    = GPIO_INTR_NEGEDGE,
    };
    ESP_ERROR_CHECK(gpio_config(&io));
    ESP_ERROR_CHECK(gpio_install_isr_service(0));
    ESP_ERROR_CHECK(gpio_isr_handler_add(PIN_BTN, btn_isr, NULL));
}

static void nvs_init(void)
{
    esp_err_t err = nvs_flash_init();
    if (err == ESP_ERR_NVS_NO_FREE_PAGES || err == ESP_ERR_NVS_NEW_VERSION_FOUND) {
        ESP_ERROR_CHECK(nvs_flash_erase());
        err = nvs_flash_init();
    }
    ESP_ERROR_CHECK(err);
}

/* ── PSRAM clip slots ────────────────────────────────────────────────────── */
static void slots_init(void)
{
    for (uint32_t i = 0; i < MAX_CLIP_SLOTS; i++) {
        if (heap_caps_get_free_size(MALLOC_CAP_SPIRAM) < CLIP_BYTES + SPIRAM_RESERVE)
            break;
        int16_t *p = heap_caps_malloc(CLIP_BYTES, MALLOC_CAP_SPIRAM);
        if (!p) break;
        g_slots[i].data  = p;
        g_slots[i].ready = false;
        g_num_slots++;
    }
    ESP_LOGI(TAG, "PSRAM: %u clip slots of %u bytes (%.1f s each), %u KB free",
             (unsigned)g_num_slots, (unsigned)CLIP_BYTES,
             (float)CLIP_SAMPLES / SAMPLE_RATE_HZ,
             (unsigned)(heap_caps_get_free_size(MALLOC_CAP_SPIRAM) / 1024));
}

/* Pick the slot to record into: first empty, else the oldest (lowest seq). */
static clip_slot_t *slot_for_recording(void)
{
    if (g_num_slots == 0) return NULL;
    clip_slot_t *oldest = &g_slots[0];
    for (uint32_t i = 0; i < g_num_slots; i++) {
        if (!g_slots[i].ready && g_slots[i].seq == 0) return &g_slots[i];
        if (g_slots[i].seq < oldest->seq) oldest = &g_slots[i];
    }
    return oldest;
}
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
void app_main(void)
{
    clock_init();
    nvs_init();              /* before gain_init — the gain choice lives here */
    gain_init();             /* before the analog front end sees any signal   */
    ESP_ERROR_CHECK(dsps_fft2r_init_fc32(NULL, FFT_SIZE));
    led_init();
    btn_init();
    slots_init();
    adc_i2s_init();

    xTaskCreatePinnedToCore(led_task,  "led",  2048, NULL, 4, NULL, tskNO_AFFINITY);
    xTaskCreatePinnedToCore(main_task, "main", 8192, NULL, 5, NULL, tskNO_AFFINITY);

    /* Bring the radio up last, well after the boot/PSRAM inrush has settled —
     * Wi-Fi RF calibration is the biggest current spike and marginal supplies
     * brown out when the spikes stack. */
    vTaskDelay(pdMS_TO_TICKS(2000));
    wifi_ap_init();
    http_init();
}
